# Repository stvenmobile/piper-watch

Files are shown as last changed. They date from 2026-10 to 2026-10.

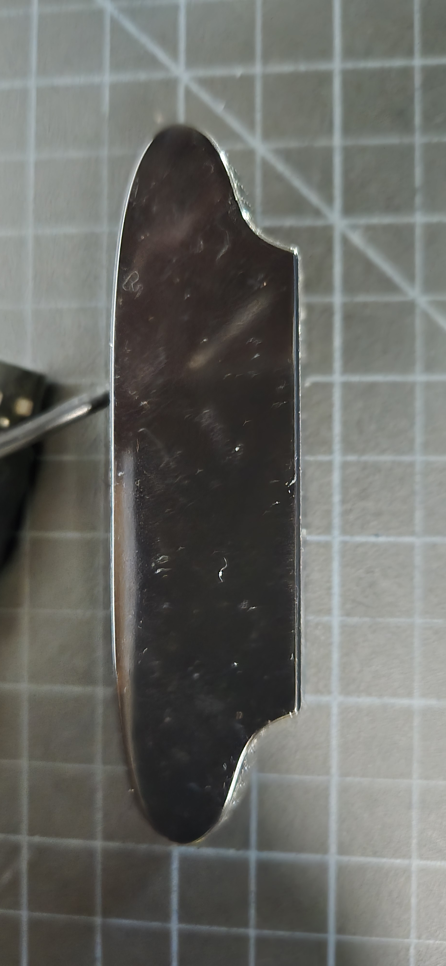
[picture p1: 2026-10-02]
hardware/cad/cam_top.jpg

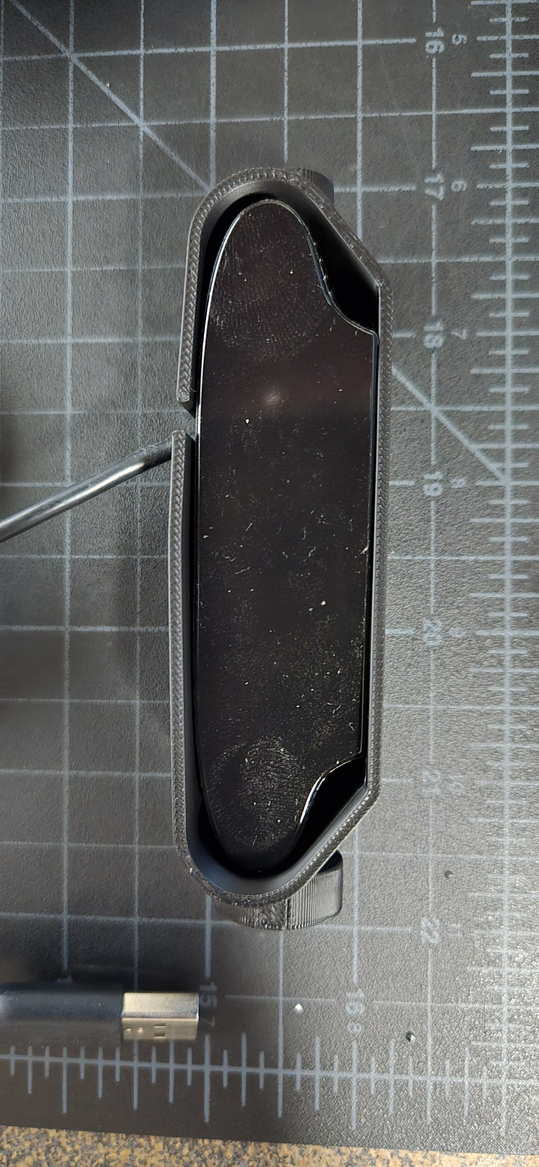
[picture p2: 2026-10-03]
hardware/cad/20261002_183955.jpg

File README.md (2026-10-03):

# Piper-Watch

**Piper-Watch** is the eyes of [piper-assistant](https://github.com/stvenmobile/piper_assistant):
a desktop robot head that turns to look around, finds and follows
faces, and recognises the people it knows. The face is deliberately not a cartoon: a round
face with the camera lens in the middle, framed by a **glowing LED ring** that shows what Piper
is doing (listening, thinking, speaking) and who it is paying attention to.

All the thinking happens on an **NVIDIA Jetson Orin NX** in a separate enclosure. Piper-Watch
itself is a compact two-part unit: a **shallow cylindrical base** (power, an ESP32-S3 controller,
the pan servo) carrying a lazy Susan, and a **head** on a short neck that turns left and right.
There is deliberately **no tilt motor**: the head is fixed at a 15° upward angle by a swappable
wedge, which suits seated conversation. Anything richer than the ring - text, status, the
camera view - goes on the Jetson's dashboard web page.

> **Status:** design phase. The servos are on order; nothing is built yet.

---

## Goals and non-goals

**Goals**
- Smooth, quiet tracking of a person's face (pan), without stepping or buzzing while holding still.
- Simple and stable: one servo, no tilt joint, everything wired inside.
- Face detection and recognition running entirely locally on the Jetson.
- A calm, clearly-a-device presence: the light ring shows Piper's state and points toward the
  person it is attending to, so it reads as an assistant, not a camera that silently watches.
  No eyes or mouth to anthropomorphise (and Piper's voice comes from the speakerphone anyway).
- Compact: a footprint barely larger than the 140 mm lazy Susan, about 20-23 cm tall.
- One data cable and one power brick between the head and the rest of the system.

**Non-goals (for now)**
- A display on the unit. Text, status and the camera view with detection overlays live on
  the Jetson's **dashboard web page** instead.
- Running any AI on the ESP32.
- Battery operation.

---

## System architecture

```text
 ┌─────────────────────── Jetson Orin NX (own enclosure + own PSU) ───────────────────────┐
 │  Vision: capture → face detection → recognition → tracking → pan target + ring state   │
 │  piper-assistant: speech in/out (Piper TTS), dialogue, events                          │
 │  Dashboard web page: camera view + boxes/names/contours (replaces the vector display)  │
 └──────────────┬───────────────────────────────────────────────┬─────────────────────────┘
                │ one USB 2.0 cable                             │ USB
                │                                               │
 ┌──────────────▼──────────── Piper-Watch ──────────────┐  ┌────▼─────────────────────┐
 │  FE1.1s USB 2.0 hub board (fed from the 5 V buck)    │  │ SP-200 speakerphone      │
 │   ├── Logitech C920X camera (stripped) - the "nose"  │  │ 4-mic array, hardware AEC│
 │   └── ESP32-S3 DevKitC-1 N16R8 (native USB)          │  │ placed away from the head│
 │          ├── GPIO 8 → level shifter → 24-LED ring    │  └──────────────────────────┘
 │          │ UART1 @ 1 Mbps (half-duplex servo bus)    │
 │          ▼                                           │
 │  Waveshare Bus Servo Adapter (A) ── 12 V ──┐         │
 │          │ servo bus (daisy-chained)        │         │
 │          └── STS3215  PAN  (ID 1)          │         │
 │                                            │         │
 │                                            │         │
 │  12 V / 5 A brick ── fuse ── star point ───┴── 5 V / 3 A buck ── USB hub power │
 └──────────────────────────────────────────────────────┘
```

The roles are:
- **Jetson:** perception and decisions. It decides *where to look*.
- **ESP32-S3:** real-time body. It decides *how to move there* smoothly and safely,
  reports where the head actually is, and animates the face.
- **Servos:** close their own position loop with a 12-bit magnetic encoder, and report
  position, load, voltage and temperature.

---

## Components

| Part | Role | Status |
|---|---|---|
| NVIDIA Jetson Orin NX (JetPack) | vision, recognition, assistant, dashboard | have |
| **ESP32-S3 DevKitC-1 N16R8** (16 MB flash, 8 MB octal PSRAM, native USB) | controller: pan motor, LED ring, link to the Jetson | have |
| **24-LED WS2812-type ring**: OD 65.6, ID 52.3, 3.2 mm with LEDs; through-hole pads 2× 5 V, 2× GND, DIN, DOUT | the face's light ring | have |
| **74AHCT125** (or a single-gate 74AHCT1G125) level shifter | ESP32 3.3 V data → 5 V ring | needed (~$1) |
| Translucent ring, printed (`ring_diffuser.scad`) in white or natural PLA/PETG | diffuser in front of the LEDs | print |
| **Feetech STS3215, 12 V / 30 kg·cm** serial bus servo: 360° magnetic encoder (4096 steps, 0.088°), position/load/voltage/temperature feedback, 1 Mbps half-duplex TTL bus (2 ordered; the second is a spare) | pan | **ordered** |
| Waveshare **Bus Servo Adapter (A)**: 9–12.6 V input, powers the servo bus and converts it to plain TX/RX for the ESP32 | servo bus interface | needed |
| Logitech **C920X**, housing partly stripped (94 × 24.1 × 29 mm) | camera - the head's "nose" | have |
| **SP-200** USB speakerphone (5 V): 4-mic array, hardware echo cancellation, USB Audio Class | microphone/speaker, connected to the Jetson | have |
| 5.5" (140 mm) aluminium lazy Susan bearing | pan base, carries all vertical load | have / needed |
| 3D-printed base, turntable plate, hollow neck, 15° wedge, and a two-part head (face front + screw-on back) | enclosure | camera pod fit-tested |
| Silicone hook-up wire, ~2 mm, very flexible (6 colours) | display wiring through the neck | have |
| **12 V / 5 A** power brick, inline 5 A fuse, 1000 µF / 25 V capacitor | head power | needed |
| **5 V / 3 A** buck converter | USB hub power | needed |
| **FE1.1s 4-port USB 2.0 hub board** (~$5–7) with external 5V/GND pads and a cuttable "Disable USB Power" jumper (e.g. [Circuitneato](https://circuitneato.com/how-to-use-the-fe1-1s-usb-hub/), or generic "FE1.1s hub module" listings) | one cable to the Jetson | needed |

---

## Power

The servos are the 12 V version, so **the servo bus runs directly from the 12 V brick**
through the Bus Servo Adapter, with no converter in that path. Only the 5 V USB side
needs a buck converter.

```text
12 V / 5 A brick ── 5 A fuse ──┬── 1000 µF ── Bus Servo Adapter (A) ── STS3215 pan servo
                               │
                               └── 5 V / 3 A buck ── FE1.1s hub (5V pads) ──┬── ESP32-S3 (native USB); 5 V → LED ring
                                                                            └── C920X camera
GND: all grounds meet at one star point at the brick input.
```

**Why this layout**
- **Isolation:** the ESP32-S3, LED ring and camera get their 5 V from their own regulator, never
  from the servo rail, so servo current spikes can't reset the ESP32 or glitch the camera. They
  also don't depend on the Jetson's USB ports for power.
- **Efficiency:** the biggest load (the servos) has no conversion losses at all. The 5 V buck
  only carries about 1 A.
- **One cable:** the hub merges the camera and the ESP32-S3 onto a single USB cable to the Jetson.

**USB hub: FE1.1s board**
- **Power:** wire the 5 V buck to the board's **5V/GND pads**. It runs self-powered, at
  500 mA per port (2 A total), which covers the ESP32-S3 (~0.1 A) and the camera (~0.5 A).
  The LED ring is wired to the buck directly, not through the hub.
- **Stop back-feeding:** **cut the "Disable USB Power" jumper** (the name and position vary by
  maker). Otherwise the buck's 5 V flows back up the cable into the Jetson's USB port.
- **Check it before connecting the Jetson:** with only the external 5 V applied, measure the
  upstream port's VBUS pin. It must read **0 V**.
- **Fallback:** the Waveshare USB-HUB-4U (metal case, 5 V DC jack, ~$15–20) works too, but its
  back-feeding behaviour isn't documented, so do the same VBUS check first.

**Power budget (estimates)**

| Load | Typical | Peak |
|---|---|---|
| STS3215 at 12 V, holding | ~0.1 A | |
| STS3215 at 12 V, moving | ~0.3–0.8 A | ~3 A if it stalls |
| ESP32-S3 (5 V) | ~0.1 A | |
| LED ring (5 V), brightness capped at ~25% | ~0.05–0.25 A | ~1.4 A if driven full white (the firmware never does) |
| C920X camera (5 V) | ~0.4 A | ~0.5 A |
| **12 V input total** | **~0.4–1.2 A** | **~3.5 A** |

Normal tracking stays well inside 5 A, and even a full stall of the single servo (jammed, or
pushing against a hard stop) stays under it. Protection:
- Set each servo's **protection current and overload limits** in its EEPROM (see Servo setup),
  so a stall is cut back long before it threatens the brick.
- The **5 A fuse** protects the wiring if something does go wrong.

**The 1000 µF capacitor** at the adapter input absorbs current spikes when the servos
start moving, so the 12 V line doesn't dip.

---

## Wiring and pins (ESP32-S3 DevKitC-1 N16R8)

Pins avoid the ones the N16R8 module and board use internally: GPIO 26-32 (flash),
33-37 (octal PSRAM), 19/20 (native USB), 43/44 (UART0, the board's "UART" port) and the
strapping pins 0, 3, 45, 46.

| Signal | ESP32-S3 pin | Goes to |
|---|---|---|
| Servo bus TX | **GPIO 17** (UART1 TX) | Bus Servo Adapter **RX** |
| Servo bus RX | **GPIO 18** (UART1 RX) | Bus Servo Adapter **TX** |
| Ground | GND | Bus Servo Adapter GND (do not connect its supply to the S3) |
| LED ring data | **GPIO 8** → 74AHCT125 (powered from 5 V) → ring **DIN** | 24-LED ring; DOUT unused |
| LED ring power | 5 V buck / GND | ring 5 V and GND pads (use both pairs) |
| Jetson link + flashing | native USB (the board's **"USB"** port, GPIO 19/20) | USB hub → Jetson, appears as `/dev/ttyACM0` |
| Status LED | on-board RGB (GPIO 48 on v1.0 boards, GPIO 38 on v1.1) | link / fault indication |

**Three wires to the head.** The ring needs only 5 V, GND and one data wire, running about
40-50 cm from the base up through the lazy Susan and the neck (plus the camera cable), so:
- **level-shift the data** to 5 V at the ESP32 end (74AHCT125): WS2812-type LEDs want a 5 V
  logic high, and 3.3 V straight down a long wire is unreliable;
- add a **330 Ω resistor** in series with the data line at the shifter output, and a
  **470-1000 µF** capacitor across 5 V/GND at the ring;
- twist the data wire with a ground wire.

Set the Bus Servo Adapter's jumper for an external UART controller (not its own USB port).
The adapter handles the half-duplex direction switching, so the ESP32 just uses normal TX/RX.

---

## Servo setup (one-time)

1. **ID:** the pan servo stays at the factory **ID 1** (the spare can be set to ID 2 if it is ever
   added). Use Feetech's FD software, the Bus Servo Adapter's USB mode, or a small ESP32 sketch.
2. **Zero before assembly, then centre.** Before fitting a horn or coupling, power each servo and
   command it to **2048 (mid position)**. Only then attach the turntable coupling with the head
   pointing **straight ahead**. That way the mechanism's centre is the servo's
   centre and nothing is under strain at rest. Afterwards, fine-tune with the middle-position
   calibration so that **2048 = straight ahead** exactly. The bench firmware has a
   `center` command for this.
3. **Angle limits in the servo's EEPROM**, so they hold even if the software misbehaves:
   - **Pan:** about ±150° from centre (the camera cable sets the real limit; see Mechanics).
4. **Protection:** set the protection current, overload torque and temperature limits, and enable
   the overload behaviour that drops torque instead of fighting.
5. **Speed and acceleration:** set sensible defaults. The ESP32 overrides them per move.

Library: Feetech's **SCServo** (`SMS_STS` class) for Arduino-ESP32, at 1 Mbps.

---

## Motion control

- The Jetson sends **targets** (pan angle plus a speed hint) at up to 30–50 Hz.
- The ESP32 clamps them to the soft limits, smooths them (a velocity and acceleration
  limit, so tracking looks natural rather than snappy), and writes goal position, speed
  and acceleration to the servo.
- The ESP32 reads back **actual position, load, voltage and temperature** at about 50 Hz,
  timestamps them, and reports them to the Jetson. The Jetson uses the timestamp to work out
  where the camera was pointing when each video frame was taken. This is what keeps tracking
  stable while the head is moving.
- **Watchdog:**
  - no message from the Jetson for **1 s** → hold position;
  - for **10 s** → ease back to the rest pose, then release torque (quiet when idle);
  - over-temperature or overload reported by a servo → stop and report.
- **Power-up:** bus servos don't jump on power-up. The ESP32 reads where they are and
  starts from there.
- **Don't force the head while it's powered.** The STS3215 has no slip clutch: twisting a head
  that is holding position by hand fights the motor and can strip its gears. Two defences:
  - the servo-side **overload and current limits** (Servo setup, step 4) drop torque instead of
    fighting;
  - **torque is released when idle** (watchdog above). To move the head by hand on purpose, release
    torque first (a command from the Jetson or the dashboard), and turn it gently.

---

## Jetson ↔ ESP32 protocol (draft)

- **Link:** the ESP32-S3's native USB serial (`/dev/ttyACM0` on the Jetson). Native USB ignores
  the baud setting and runs at full USB speed.
- **Framing:** binary messages, **COBS**-framed with a **CRC-16**, each with a type byte and a
  sequence number. Unknown types are ignored, so either side can be updated first.

| Direction | Message | Contents |
|---|---|---|
| Jetson → ESP32 | `HEARTBEAT` | sequence, Jetson time |
| Jetson → ESP32 | `LOOK` | pan°, max speed, mode (track / glance / rest) |
| Jetson → ESP32 | `FACE` | state (idle, listening, thinking, speaking, sleeping, error, …), attention direction, colour/brightness |
| Jetson → ESP32 | `CONFIG` | soft limits, smoothing, ring brightness limit, etc. |
| ESP32 → Jetson | `STATUS` | actual pan, load, voltage, temperature, ESP32 time, flags |
| ESP32 → Jetson | `EVENT` | watchdog/fault, boot |

The message set stays small: no video or vector data crosses this link.

---

## The face

A round face (about 105 mm across - the smallest circle around the camera) with the camera lens
in the middle, framed by a glowing ring. The ring is a 24-LED WS2812-type ring behind a
translucent diffuser, and the ESP32-S3 animates it from a single state (`FACE` message):

| State | Ring |
|---|---|
| **Idle** | a steady, soft warm glow |
| **Listening** | slow "breathing" |
| **Thinking** | a short comet running around the ring |
| **Speaking** | a quick, slightly irregular pulse while Piper's TTS plays |
| **Attention** | a brighter arc pointing toward the person being tracked |
| **Sleeping** | a dim ember |
| **Error** | amber flashes |

Brightness is capped at about 25%: plenty behind the diffuser, easy on the 5 V supply, and a
soft warm-white ring also lights the person's face a little, which helps detection in a dim
room. (No red ring - that reads as HAL 9000.)

**Light path.** From the face inward: a 2 mm **diffuser ring** (printed in white or natural
filament, pressed in flush with the face) → a 3.5 mm **air gap** where each LED's light spreads
into its neighbours → the LEDs, facing forward. The ring sits in a pocket behind the gap, held
with a few dabs of hot glue. Its four power pads (15 mm apart) go at the **top** and the two data
pads at the **bottom**; single header pins soldered into the pads take Dupont plugs, which point
straight back above and below the camera (never at the sides, where the camera is right
behind the ring).
Three thin spokes cross the air gap to hold the centre of the face; they fall between LEDs.
The camera sits just behind the ring, its lens at the bottom of a flared opening (16 mm at
the lens, 31 mm at the face, so it doesn't clip the view). Everything else - text, status, the
live camera view with boxes and names - goes on the Jetson's **dashboard web page**.

---

## Vision pipeline (Jetson)

- **Capture:** C920X via V4L2, MJPEG at 720p30 (1080p if needed). Once mounted, **lock focus and
  exposure** with `v4l2-ctl`, because autofocus hunting looks bad while tracking.
- **Face detection:** SCRFD or a YOLOv8-face model under **TensorRT**.
- **Recognition:** **ArcFace** embeddings (InsightFace), matched against a local gallery.
  **Enrolment** is a short guided capture of several angles. Embeddings stay on the Jetson, and
  a "forget me" command deletes a person.
- **Tracking:** keep a track ID per face. Turn the face's **horizontal** position into a pan
  target using the camera's field of view and the head pose *at the time of that frame* (from
  `STATUS`), with a deadband so the head isn't constantly making tiny corrections. **Vertically**
  there is no motor: the camera's ±21° view around its fixed 15° tilt covers seated faces, and
  the Jetson can crop the 1080p frame to centre on it.
- **Behaviour (piper-assistant):** who to look at (speaker, newcomer, recognised person),
  idle glances, a rest pose, and ring states that match the conversation.

---

## Mechanics

Pan only - no tilt motor. Bottom to top:

- **Base:** a shallow cylinder about 146 mm across and 8 cm tall, just larger than the lazy Susan.
  It holds the ESP32-S3, Bus Servo Adapter, 5 V buck and USB hub, with the pan servo in the middle
  and the power input and USB cable at the back. Its top has the raised plinth (outer ring only)
  with M5 heat-set inserts.
- **Pan:** the lazy Susan carries all the weight above it. The pan servo only *turns* the
  turntable plate (on the inner ring) through a coupling at the centre, so there's no sideways
  load on the servo shaft. Soft limits about ±150°.
- **Neck:** a short hollow, chamfered square column (about 40 × 40 mm outside, **28 × 28 mm inside**)
  on the turntable plate. Every wire to the head runs inside it.
- **Wedge:** a small printed block between neck and head, hollow for the wires, that sets the
  head's fixed **15° upward tilt** for seated conversation. To change the angle, print another
  wedge (10°, 20°, ...) and swap it - two or three screws. There's no hinge, so nothing can creep.
- **Head:** round, about 105 mm across and about 45 mm deep, in two parts:
  - **Front (the face):** carries everything: the flared lens opening in the middle, the LED ring
    and its diffuser around it, and the camera cradle behind.
  - **Back cover:** encloses the electronics and wiring and **screws onto the front** (M3 screws into
    heat-set inserts). Assembly and repair: mount the parts to the face, plug in, feed the wires
    down through the wedge and neck, screw on the back.
- **Cables:** the camera's USB cable plus the ring wiring (three 2 mm silicone hook-up wires:
  5 V, GND, data) run from the head down the neck, through the lazy
  Susan's 89 mm opening, into the base, with a **service loop** in the base for the ±150° of pan.
  Nothing is visible from outside. Avoid slip rings for USB 2.0.
- **Noise:** the STS3215 is quiet when holding still. If movement noise still reaches the
  speakerphone, have piper-assistant pause or flag speech recognition while the head moves.

---

## Repository layout

```text
firmware/head/   PlatformIO project for the ESP32-S3 controller (pan motor, LED ring, Jetson link)
jetson/          Jetson-side Python: vision, tracking, head link, dashboard
hardware/        CAD for printed parts, wiring diagrams
docs/            design notes, protocol spec
tools/           servo ID / calibration helpers, bench tests
```

Face images and embeddings are never committed (`jetson/data/` is git-ignored), because this
repository is public.

---

## Roadmap

1. **Bench:** ESP32-S3 + pan motor driver, plus the LED ring through its level shifter. Move by
   serial command; bring up the ring states.
2. **Head v1:** printed base, turntable plate, neck, wedge and two-part head; pan servo, limits,
   watchdog, `STATUS` reporting.
3. **Face:** ring states, the attention arc that follows the tracked person, and the `FACE` message.
4. **Vision:** detection and tracking on the Jetson closing the loop through `LOOK`.
5. **Recognition:** enrolment, gallery, names on the dashboard and in the assistant.
6. **Dashboard:** camera view with overlays on the Jetson's web page.

## Open questions

- Final pan range, which depends on the cable routing.
- Diffuser: filament and thickness for an even glow (print a test ring first).
- Pan drive: central direct drive or offset belt (affects cable routing through the base).

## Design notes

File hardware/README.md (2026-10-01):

# Hardware

- `cad/`: 3D-printable parts (tilt yoke, camera housing, pan coupling, enclosure)
- `wiring/`: wiring diagrams and photos

The bill of materials, power design and pin table are in the main README.

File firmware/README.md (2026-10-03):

# Firmware

`head/` is the PlatformIO project for the controller, an **ESP32-S3 DevKitC-1 N16R8**
(16 MB flash, 8 MB octal PSRAM). It drives the STS3215 servo bus, animates the two OLED eyes
and talks to the Jetson over native USB serial.

Connect the board's **"USB"** port (native USB, not the "UART" port), then:

    cd firmware/head
    pio run -t upload        # build and flash
    pio device monitor       # serial output

The current sketch is a face bring-up test: it reports whether each display answers (eyes on
I2C0 at 0x3C / 0x3D, SDA 8 / SCL 9; mouth on I2C1 at 0x3C, SDA 10 / SCL 11), then the eyes blink
and glance while the mouth alternates between talking and smiling.

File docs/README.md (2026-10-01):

# Docs

Design notes that outgrow the main README, for example the full Jetson ↔ head protocol spec
and servo calibration records. Reference: [LCDWiki E32R40T](https://www.lcdwiki.com/4.0inch_ESP32-32E_Display).

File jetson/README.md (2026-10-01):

# Jetson side

Runs on the Jetson Orin NX. Planned modules:

- `piper_watch/link.py`: the Jetson ↔ head protocol (COBS + CRC-16 over USB serial)
- `piper_watch/vision/`: capture, face detection (SCRFD / YOLOv8-face) and recognition (ArcFace)
- `piper_watch/track.py`: turns face positions into pan/tilt `LOOK` targets
- dashboard: camera view with overlays, served on the Jetson

Face images and embeddings live in `jetson/data/`, which is git-ignored and never leaves the Jetson.

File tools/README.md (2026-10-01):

# Tools

Helper scripts, for example setting STS3215 IDs (new servos all ship as ID 1),
writing angle limits and centre calibration, and a bench test for the servo bus.

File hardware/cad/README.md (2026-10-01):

# CAD (OpenSCAD)

All printed parts are parametric OpenSCAD models. Every dimension lives in
[`params.scad`](params.scad); change a number there and every part follows.

```text
params.scad          dimensions, clearances, printer settings (EST = estimate, to be measured)
vitamins/            simple models of bought parts (lazy Susan, STS3215, ...) for fit checks
parts/               printable parts, one file each
assembly.scad        everything together, to check fit and range of motion
export.sh            render parts/ to out/*.3mf for Bambu Studio
```

## Setup

1. Install an OpenSCAD **development snapshot** (openscad.org → Downloads → Development
   Snapshots), not the old 2021.01 release.
2. *Edit → Preferences → Advanced → Backend:* **Manifold**. Full renders take seconds instead of minutes.
3. Later parts will use the **BOSL2** library (rounded edges, screw holes, attachments). Install
   it into OpenSCAD's library folder (*File → Show Library Folder*) as `BOSL2`.

In OpenSCAD, **F5** previews (fast, for looking), **F6** renders (exact), and **F7** exports
the rendered part.

## Print first

1. **`parts/tolerance_coupon.scad`**: tells us the hole clearance and heat-set insert bore that
   work on this printer with PETG. Update `clr_hole`, `insert_m3` and `insert_m4`.
2. **`parts/ls_gauge.scad`**: a 2 mm ring with slotted holes and tick marks. Lay it on the
   real lazy Susan and read off the true bolt-circle diameters (the numbers next to the ticks).
   Update `ls_outer_bc`, `ls_inner_bc` and `ls_hole_d`.

Then every later part (pan base, turntable top, tilt yoke, camera cradle, box) is built on
measured numbers.

## Printing defaults (A1, 0.4 mm nozzle, PETG)

- At least 4 walls (about 1.8 mm) on load-bearing parts.
- Orient parts so the load runs along the layers, not across them.
- Use M3/M4 brass heat-set inserts where screws go in more than once.

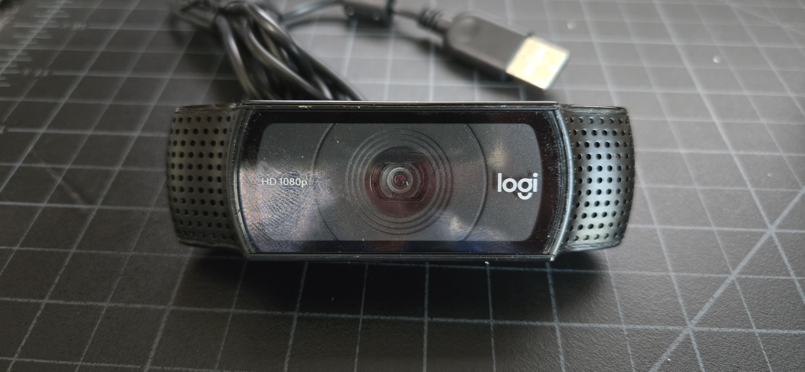
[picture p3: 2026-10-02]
hardware/cad/cam_front.jpg

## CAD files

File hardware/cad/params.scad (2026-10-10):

// Piper-Watch - all dimensions in one place (millimetres).
// Values marked EST are estimates; correct them after measuring the real part.

$fn = 96;                        // circle smoothness for previews/exports

// --- Printing: Bambu Lab A1, 0.4 mm nozzle, PETG -------------------------------
line_w      = 0.45;              // extrusion width
wall        = 4 * line_w;        // 1.8 mm: minimum for load-bearing walls
bed         = [225, 225, 225];   // build volume
clr_hole    = 0.30;              // added to bolt hole diameters - measured: +0.3 is the smallest free fit (coupon, 2026-10-01)
// FIT CALIBRATION (fit_calibration.scad; 15% gyroid, 4 walls, 5 top/bottom; Bambu profiles with
// NO slicer compensation - the CAD compensates). Pick the material the part is printed in:
material   = "PETG";             // "PETG" = Bambu PETG Basic (base parts), "PLA" = Bambu PLA Basic
//   PLA  (2026-10-04): holes ~0.4 small on the diameter (4..15 mm); pins/outer edges ~0.1 small;
//                      X/Y -0.45% (80 -> 79.6 / 79.7); Z true.
//   PETG (2026-10-07): holes 0.29..0.48 small (mean 0.39; 4..6 mm ~0.46, 8..15 mm ~0.32);
//                      pins 0.19..0.22 small; X/Y -0.30% (79.74 / 79.78); Z true (30.02);
//                      first layer slightly squashed (4.00 plate -> 4.11).
cal_hole   = 0.4;                                    // add to a hole's diameter to get it as drawn
cal_edge   = material == "PLA" ? 0.1 : 0.2;          // add to an outside dimension
cal_xy     = material == "PLA" ? 1.0045 : 1.0030;    // scale long X/Y distances (bolt circles, spans)
hole_shrink = 0.6;               // MEASURED on the turntable pulley (PLA, 15% gyroid, 4 walls): a 6.0 hole printed 5.4.
                                 //   Larger PLA parts: draw a hole this much bigger than the size you want.
clr_fit     = 0.35;              // gap for parts that slide/rotate against each other (a little looser than clr_hole)

// --- Fasteners ------------------------------------------------------------------
m3          = 3.0;
m4          = 4.0;
insert_m3   = [4.1, 5.0];        // heat-set insert bore [diameter, depth] - coupon "M3a" confirmed
insert_m25  = [3.6, 4.5];        // EST - M2.5 inserts (~3.5 OD): print a coupon before the body
insert_m4   = [5.6, 6.0];        // coupon "M4a" confirmed
m5          = 5.0;
insert_m5   = [6.4, 7.0];        // EST - confirm with parts/m5_coupon.scad

// --- Lazy Susan: 140 mm round aluminium turntable bearing (Amazon B08CSMCRC6) ----
// Two COPLANAR rings, both 10.5 mm thick and flush top and bottom, with a 0.8 mm gap.
// The outer ring screws down into the box (countersinks on top); the inner ring
// screws up into the turntable top plate (countersinks underneath). No access hole.
ls_od        = 140;              // outer ring, outside (measured)
ls_ring_w    = 12.4;             // radial width of each ring (measured)
ls_gap       = 0.8;              // radial gap between the rings (measured)
ls_outer_id  = ls_od - 2 * ls_ring_w;            // 115.2  outer ring, inside
ls_inner_od  = ls_outer_id - 2 * ls_gap;         // 113.6  inner ring, outside
ls_id        = ls_inner_od - 2 * ls_ring_w;      // 88.8   centre opening (measured ~89)
ls_h         = 10.5;             // thickness of both rings (measured)
ls_hole_d    = 5.05;             // through holes, countersunk (measured 5.05; M5 passes) -> M5 flat-head screws
ls_outer_bc  = 128.0;            // measured: 133 edge-to-edge across opposite holes - hole dia (ring-centre estimate 127.6)
ls_inner_bc  = 101.0;            // measured: 106 edge-to-edge across opposite holes - hole dia (ring-centre estimate 101.2)
ls_holes     = 4;                // per ring, 90 degrees apart
ls_inner_rot = 45;               // inner holes sit between the outer ones

// Mounting rules that follow from the flush rings
ls_clear     = 1.0;              // keep printed parts this far (diameter) from the other ring
top_plate_d  = ls_inner_od - ls_clear;           // 112.6  turntable plate touches the inner ring only
plinth_id    = ls_outer_id + ls_clear;           // 116.2  box-top plinth touches the outer ring only
plinth_h     = 2.0;              // raised plinth height = clear gap under the inner ring

// --- Feetech STS3215 (12 V / 30 kg.cm) - EST from datasheet, verify on arrival --
sts_body     = [45.2, 24.7, 35]; // length x width x height (without horn)
sts_shaft_x  = 11.5;             // EST: output shaft centre from the near end
sts_horn_d   = 20;               // EST: horn diameter
sts_horn_h   = 3;

// --- Pan-only head on a neck (no tilt motor) ----------------------------------------
head_size    = [105, 45, 105];   // round face: diameter, depth (final ~45), diameter
head_tilt    = 15;               // fixed upward tilt, set by the swappable wedge
neck_out     = 40;               // EST: chamfered square neck, outside
neck_in      = 28;               // inside opening: camera USB plug + ~10 x 2 mm silicone wires

// --- GT2 timing belt (6 mm) and printed pulley teeth -----------------------------------
// Tooth-space shape is tunable: print parts/pulley_test_arc.scad and adjust until the belt
// seats fully with no rocking.
gt2_pitch    = 2.0;              // tooth pitch
gt2_pld      = 0.254;            // pitch line sits this far outside the pulley's tooth tips
gt2_belt_w   = 6.0;              // belt width
gt2_belt_t   = 1.5;              // belt total thickness, teeth included (measured)
gt2_tooth_h  = 0.75;             // belt tooth height
gt2_depth    = gt2_tooth_h + 0.05;   // tooth-space depth (belt tooth + clearance) - fits (test arc 1)
gt2_tip_r    = 0.555 + 0.05;     // rounded bottom of the tooth space
gt2_mouth    = 1.35;             // tooth-space width at the tips

// --- Face LED ring: 24-LED WS2812-type ring (measured / vendor) ------------------------
// Through-hole pads (2x 5 V, 2x GND, DIN, DOUT); wires can leave from either side.
ring_od      = 65.6;             // outer diameter
ring_id      = 52.3;             // inner diameter
ring_t       = 3.2;              // PCB (1.6) + 5050 LEDs
ring_n       = 24;               // LEDs, 15 deg apart (~7.7 mm)

// Diffuser in front of the LEDs (ring_diffuser.scad), pressed into the face flush
diff_t       = 2.0;              // thickness
diff_w       = 6.5;              // radial width
diff_clr     = [0.25, 0.45];     // [inner, outer] clearance each side. Fit test 3: diffuser 0.15/0.15 bound
                                 //   at both edges. Then 0.25/0.25 printed 53.2 / 64.5 but the stand's seat
                                 //   printed 52.2 / 64.2 (outer wall at the bed shrinks) -> outer 0.45: CONFIRMED, drops in smoothly

// --- Eyes: 1.28" round TFT, 240 x 240, GC9A01, SPI (MTDELE; vendor listing - re-check on arrival).
// The board is ROUND, concentric with the display, plus a tab carrying the 7 pins.
eye_board_d  = 37.5;             // round board
eye_glass_d  = 35.3;             // round glass, concentric
eye_active_d = 32.4;             // visible (pixel) circle
eye_tab      = [22.7, 8.0];      // pin tab: width, length beyond the circle (overall height 45.5)
eye_t        = 3.2;              // board + glass, without pins
eye_tab_hole_d = 2.0;            // EST: two small holes at the tab's outer corners
eye_tab_hole_x = 9.0;            // EST: their distance either side of the centre line

// --- Mouth: 2.08" white OLED, 256 x 64, SH1122, 4-wire SPI (GME25664-65; vendor drawing:
// 2_08-white_OLED_2.jpg). X along the board's length, from the pin end; Y across.
oled_pcb     = [75.5, 20.6];     // board
oled_t       = 5.6;              // max, board + glass (board 1.2)
oled_holes   = [72.0, 15.5];     // 4 x d2.5 mounting holes, centred on the board
oled_hole_d  = 2.5;
oled_glass   = [62.5, 20.6, 1.63];   // glass starts 7.25 from the pin end
oled_glass_x = 7.25;
oled_va      = [53.18, 14.78];   // visible area: starts 7.25 + 2.10 from the pin end, centred across
oled_va_x    = 7.25 + 2.10;
oled_aa      = [51.18, 12.78];   // active (pixel) area, 1 mm inside the visible area
oled_va_dx   = oled_va_x + oled_va[0] / 2 - oled_pcb[0] / 2;   // -1.82: visible area's centre, off the board's
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

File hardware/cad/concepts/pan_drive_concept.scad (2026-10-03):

// Pan drive concept - ROUGH DRAFT for discussion, not a printable part.
// Stack, bottom to top: reComputer J4012 case -> saddle (air gap over its ribbed top) -> base
// (NEMA17 + belt + electronics) -> lazy Susan -> turntable plate with the hanging ring pulley
// -> neck. Origin: centre of the lazy Susan's bottom face. F5 to look around.
include <../params.scad>
use <../vitamins/lazy_susan.scad>

show_base_shell = true;      // set false to see inside
cutaway         = true;      // cut the base shell in half
show_top        = true;      // lazy Susan, turntable plate, neck and the base's top deck

// ---- sizes (draft) ---------------------------------------------------------------
case_sz   = [121, 130, 61];  // reComputer J4012
saddle_h  = 13;              // air gap over the ribbed top
base_h    = 52;              // base: from saddle deck to the plinth top
plinth_h2 = 2;

ring_T    = 100;             // ring pulley teeth (GT2, 2 mm pitch)
motor_T   = 20;              // motor pulley teeth
R  = ring_T * 2 / PI / 2;    // 31.8  pitch radius
r  = motor_T * 2 / PI / 2;   //  6.4
C  = 45;                     // centre distance (slotted mount: tension by sliding the motor out)
motor_dir = 45;              // motor sits on the diagonal, inside the case footprint
belt_w  = 6;
belt_z  = -14;               // belt plane (below the lazy Susan, inside the base)
nema    = [42.3, 42.3, 23];  // pancake NEMA17
hollow_d = 48;               // cable passage through the ring pulley

// belt length for this centre distance (closed loop)
belt_L = 2 * sqrt(C^2 - (R - r)^2) + PI * (R + r) + 2 * (R - r) * asin((R - r) / C) * PI / 180;
echo(ratio = ring_T / motor_T, belt_length_mm = belt_L, belt_teeth = belt_L / 2,
     open_belt_travel_deg = 180 - acos((R - r) / C) - 18);

z_case_top = -base_h - saddle_h;

module rbox(sz, r = 6) {     // rounded box, centred in XY, from z = 0
    linear_extrude(sz[2]) offset(r = r) square([sz[0] - 2 * r, sz[1] - 2 * r], center = true);
}

// ---- Jetson case --------------------------------------------------------------------
color("#2a2a2a") translate([0, 0, z_case_top - case_sz[2]]) rbox(case_sz, 5);
color("#3a3a3a") for (x = [-56 : 4 : 56])                       // ribs on its top
    translate([x, 0, z_case_top - 0.5]) cube([2, case_sz[1] - 8, 1], center = true);

// ---- saddle: rim that grips the case top, posts at the corners, open sides for air -----
color("#9aa0a6") translate([0, 0, z_case_top - 6]) difference() {
    rbox([case_sz[0] + 4, case_sz[1] + 4, saddle_h + 6], 7);
    translate([0, 0, -1]) rbox([case_sz[0], case_sz[1], 7], 5);              // grips the case
    translate([0, 0, -1]) rbox([case_sz[0] - 6, case_sz[1] - 6, saddle_h + 10], 4);
    for (a = [0, 90]) rotate(a) translate([0, 0, 6 + saddle_h / 2])        // airflow windows
        cube([200, 90, saddle_h - 4], center = true);
}

// ---- base shell -----------------------------------------------------------------------
if (show_base_shell) color("#b8bcc0", 0.55) difference() {
    translate([0, 0, -base_h]) difference() {
        rbox([case_sz[0] + 4, case_sz[1] + 4, base_h], 7);
        translate([0, 0, 2.5]) rbox([case_sz[0] - 1, case_sz[1] - 1, base_h], 5);
    }
    translate([0, 0, -10]) cylinder(d = ls_id - 4, h = 20);             // centre opening
    if (cutaway) translate([-100, -200, -100]) cube([200, 200, 200]);
}
// top deck with the plinth the lazy Susan's OUTER ring screws to
if (show_top) color("#b8bcc0") difference() {
    translate([0, 0, -plinth_h2 - 3]) rbox([case_sz[0] + 4, case_sz[1] + 4, 3], 7);
    translate([0, 0, -10]) cylinder(d = ls_id - 4, h = 20);
    if (cutaway) translate([-100, -200, -100]) cube([200, 200, 200]);
}
if (show_top) color("#b8bcc0") translate([0, 0, -plinth_h2]) difference() {
    cylinder(d = ls_od, h = plinth_h2);
    translate([0, 0, -1]) cylinder(d = plinth_id, h = 5);
    if (cutaway) translate([-100, -200, -100]) cube([200, 200, 200]);
}

// ---- lazy Susan + turntable plate + neck ------------------------------------------------
if (show_top) lazy_susan();
if (show_top) color("#d0d4d8") translate([0, 0, ls_h]) difference() {                 // turntable plate
    cylinder(d = top_plate_d, h = 4);
    translate([0, 0, -1]) cylinder(d = hollow_d, h = 6);
}
if (show_top) color("#d0d4d8") translate([0, 0, ls_h + 4]) difference() {             // neck stub
    linear_extrude(35) offset(r = 3) square(34, center = true);
    translate([0, 0, -1]) cube([28, 28, 40], center = true);
}

// ---- ring pulley: a tube hanging from the plate through the bearing, teeth at the bottom --
color("#e8a33d") difference() {
    union() {
        translate([0, 0, belt_z + belt_w / 2 + 1]) cylinder(d = 2 * R + 6, h = ls_h - belt_z - belt_w / 2 - 1);  // tube
        translate([0, 0, belt_z - belt_w / 2 - 1.5]) cylinder(d = 2 * R + 5, h = 1.5);   // lower flange
        translate([0, 0, belt_z + belt_w / 2]) cylinder(d = 2 * R + 5, h = 1);            // upper flange
        translate([0, 0, belt_z - belt_w / 2]) difference() {                            // teeth (simplified)
            cylinder(d = 2 * R - 0.5, h = belt_w, $fn = ring_T * 2);
            for (i = [0 : ring_T - 1]) rotate(i * 360 / ring_T) translate([R, 0, -1]) cylinder(d = 1.1, h = belt_w + 2, $fn = 8);
        }
    }
    translate([0, 0, -50]) cylinder(d = hollow_d, h = 100);
}
color("white") rotate(motor_dir + 180) translate([R - 4, 0, belt_z - belt_w / 2 - 1.5]) cylinder(d = 4, h = 1.6);   // homing magnet

// ---- belt ------------------------------------------------------------------------------
color("#222") translate([0, 0, belt_z - belt_w / 2]) linear_extrude(belt_w) difference() {
    hull() { circle(r = R + 1.2); rotate(motor_dir) translate([C, 0]) circle(r = r + 1.2); }
    hull() { circle(r = R); rotate(motor_dir) translate([C, 0]) circle(r = r); }
}

// ---- motor, pulley and slotted mount -----------------------------------------------------
rotate(motor_dir) translate([C, 0, 0]) {
    pulley_bottom = belt_z - belt_w / 2 - 8;                             // hub below the teeth
    color("#555") translate([0, 0, pulley_bottom - 3 - nema[2]]) rbox(nema, 3);
    color("silver") translate([0, 0, pulley_bottom - 1]) cylinder(d = 5, h = 20);   // shaft
    color("#c0c0c0") translate([0, 0, pulley_bottom]) {
        cylinder(d = 16, h = 7);                                         // hub + set screws
        translate([0, 0, 7]) cylinder(d = 2 * r, h = belt_w + 2, $fn = motor_T * 2);
        translate([0, 0, 7]) cylinder(d = 2 * r + 4, h = 0.8);
        translate([0, 0, 7 + belt_w + 1.2]) cylinder(d = 2 * r + 4, h = 0.8);
    }
}
// motor bracket: a shelf from the base wall that the motor's face screws to (slots: slide out
// to tension the belt); the motor hangs below it
color("#8899aa") rotate(motor_dir) translate([C, 0, belt_z - belt_w / 2 - 8 - 3]) difference() {
    translate([-25, -25, 0]) cube([50 + 22, 50, 3]);
    translate([0, 0, -1]) cylinder(d = 23, h = 5);                       // motor's centring boss
    for (sx = [-1, 1], sy = [-1, 1]) hull()
        for (dx = [-3, 3]) translate([sx * 15.5 + dx, sy * 15.5, -1]) cylinder(d = 3.4, h = 5, $fn = 16);
}

// ---- homing sensor (Hall, A3144 / or a plotter endstop) ------------------------------------
color("#3355cc") rotate(motor_dir + 180) translate([R + 4.5, 0, belt_z - belt_w / 2 - 9]) cube([4, 5, 6], center = true);

// ---- electronics (placeholders) ---------------------------------------------------------
module board(pos, sz, col, rot = 0) { color(col) translate(pos) rotate(rot) translate(-[sz[0], sz[1], 0] / 2) cube(sz); }
board([-38, 20, -base_h + 3], [25.5, 63, 12], "#1f6f3f", 0);     // ESP32-S3 DevKitC-1
board([ 35, -38, -base_h + 3], [20, 15, 12], "#7a1f9a");          // TMC2209 module + heatsink
board([-30, -40, -base_h + 3], [43, 21, 14], "#1f4f9f", 0);       // 12 V -> 5 V buck
board([ 5, -45, -base_h + 3], [30, 25, 6], "#2f2f2f");            // FE1.1s USB hub

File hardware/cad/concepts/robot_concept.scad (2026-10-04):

// Whole-robot concept - ROUGH DRAFT for discussion, not a printable part.
// The reComputer J4012 sits on the desk, unmodified. Over it drops a SKIRT (full panels front and
// sides, two short returns at the back corners so the case can't move and its DC jack / USB-C
// stay clear) that carries LEVEL 2: the pan drive, ESP32, driver, buck and the CYD status
// display. On top: lazy Susan, turntable plate + ring pulley, neck, 15 deg wedge and the round
// head. Unplug the cables and the whole robot lifts straight off the Jetson.
// Origin: desk surface under the centre of the case; +Y = front (the Jetson's ports face -Y).
include <../params.scad>
use <../vitamins/lazy_susan.scad>
use <../parts/turntable_pulley.scad>

cutaway = false;          // true: cut away the front half to see inside

// ---- the Jetson ---------------------------------------------------------------------
case_sz = [130.1, 121.1, 58.1];   // measured on the desk (model: 130.1 x 121.1)
case_r  = 8;                      // EST corner radius - take the real value from the case

// ---- skirt + level 2 (draft sizes) -------------------------------------------------------
fit     = 1.0;                    // skirt clearance around the case
skirt_t = 2.5;                    // skirt wall
air_gap = 13;                     // above the Jetson's lid (its fan draws air from there)
return_len = 12;                  // back returns, measured from each back corner
deck    = [146, 146];             // level 2 footprint: covers the 140 mm lazy Susan
lvl2_h  = 55;                     // tall enough for the CYD in its front face
cyd     = [86, 50];               // 2.8" CYD board (landscape)
cyd_win = [61, 46];               // its screen

z_lvl2  = case_sz[2] + air_gap;           // underside of level 2's floor (71.1)
z_top   = z_lvl2 + lvl2_h;                // top of level 2 (126.1)
z_ls    = z_top + plinth_h;               // lazy Susan's underside (on the plinth)

module rrect(sz, r) { offset(r = r) square([sz[0] - 2 * r, sz[1] - 2 * r], center = true); }

// ---- Jetson case ----------------------------------------------------------------------
color("#2a2a2a") linear_extrude(case_sz[2]) rrect(case_sz, case_r);
color("#3a3a3a") for (x = [-58 : 4 : 58]) translate([x, 0, case_sz[2] - 0.5]) cube([2, case_sz[1] - 10, 1], center = true);
// its back panel: DC jack (left), USB / RJ45 (middle), USB-C (right) - from the STEP model
color("#888") translate([0, -case_sz[1] / 2 - 0.2, 0]) {
    translate([-48, 0, 30]) rotate([90, 0, 0]) cylinder(d = 8, h = 1);              // DC jack
    for (x = [-15, 2]) translate([x, -1, 33]) cube([13, 1, 15]);                    // USB stacks
    translate([18.5, -1, 33]) cube([16, 1, 14]);                                     // RJ45
    translate([38.5, -1, 36]) cube([8, 1, 3]);                                       // USB-C
}

// ---- skirt ------------------------------------------------------------------------------
module skirt_2d() {
    inner = case_sz + [2, 2] * fit;
    outer = inner + [2, 2] * skirt_t;
    difference() {
        rrect(outer, case_r + fit + skirt_t);
        rrect(inner, case_r + fit);
        // open back, except a return_len wrap at each corner
        translate([0, -outer[1] / 2]) square([outer[0] - 2 * (case_r + return_len), 2 * skirt_t + 4 * fit], center = true);
    }
}
color("#c9ccd0") difference() {
    linear_extrude(z_lvl2) skirt_2d();
    // vent slots high on the side panels, level with the air gap over the Jetson's lid
    for (sx = [-1, 1], y = [-40 : 10 : 40])
        translate([sx * (case_sz[0] / 2 + 3), y, case_sz[2] + air_gap / 2]) cube([10, 5, air_gap - 3], center = true);
    if (cutaway) translate([-200, 0, -1]) cube([400, 200, 400]);
}

// ---- level 2 -------------------------------------------------------------------------------
color("#c9ccd0") difference() {
    translate([0, 0, z_lvl2]) linear_extrude(lvl2_h) rrect(deck, 10);
    translate([0, 0, z_lvl2 + 3]) linear_extrude(lvl2_h - 6) rrect(deck - [6, 6], 7);        // hollow
    translate([0, 0, z_top - 4]) cylinder(d = ls_id - 4, h = 10);                         // centre opening
    translate([0, deck[1] / 2, z_lvl2 + lvl2_h / 2]) cube([cyd_win[0], 10, cyd_win[1]], center = true);
    for (sx = [-1, 1], y = [-50 : 10 : 50])                                                // level 2 vents
        translate([sx * deck[0] / 2, y, z_lvl2 + 15]) cube([10, 5, 12], center = true);
    if (cutaway) translate([-200, 0, -1]) cube([400, 200, 400]);
}
color("#c9ccd0") translate([0, 0, z_top]) difference() {                                  // plinth
    cylinder(d = ls_od, h = plinth_h); translate([0, 0, -1]) cylinder(d = plinth_id, h = 5);
}
// CYD behind its window
color("#1d3b6e") translate([0, deck[1] / 2 - 3 - 4, z_lvl2 + lvl2_h / 2]) cube([cyd[0], 2, cyd[1]], center = true);
color("#9cc4ff") translate([0, deck[1] / 2 - 2.9, z_lvl2 + lvl2_h / 2]) cube([cyd_win[0] - 2, 0.2, cyd_win[1] - 2], center = true);

// ---- drive (as in pan_drive_concept / turntable_pulley) -------------------------------------
translate([0, 0, z_ls]) lazy_susan();
// the real turntable pulley part, flipped from its print orientation (plate up, tube down)
z_plate_top = z_ls + ls_h + 8;
color("#e8a33d") translate([0, 0, z_plate_top]) mirror([0, 0, 1]) turntable_pulley();
z_belt = z_ls + ls_h - 24.5;
motor_a = -135;                                // motor in a back corner (clear of the CYD)
C = 45; r_m = 20 / PI;
rotate(motor_a) translate([C, 0, 0]) {
    color("#555") translate([0, 0, z_belt - 3 - 8 - 3 - 23]) linear_extrude(23) rrect([42.3, 42.3], 3);
    color("#bbb") translate([0, 0, z_belt - 3 - 8]) cylinder(d = 16, h = 8 + 7);
}
color("#222") translate([0, 0, z_belt - 3]) linear_extrude(6) difference() {
    hull() { circle(r = 33); rotate(motor_a) translate([C, 0]) circle(r = r_m + 1.2); }
    hull() { circle(r = 31.8); rotate(motor_a) translate([C, 0]) circle(r = r_m); }
}
// boards (placeholders): ESP32, stepper driver, buck
color("#1f6f3f") translate([-58, -35, z_lvl2 + 3]) cube([25.5, 63, 12]);
color("#7a1f9a") translate([28, 30, z_lvl2 + 3]) cube([20, 15, 12]);
color("#1f4f9f") translate([30, -10, z_lvl2 + 3]) cube([22, 43, 12]);

// ---- neck, wedge, head ------------------------------------------------------------------------
neck_h = 40;
color("#c9ccd0") translate([0, 0, z_plate_top]) difference() {
    linear_extrude(neck_h) rrect([40, 40], 4);
    translate([0, 0, -1]) cube([28, 28, neck_h + 2], center = true);
}
head_d = head_size[0]; head_depth = 45;
translate([0, 0, z_plate_top + neck_h]) rotate([-15, 0, 0]) translate([0, 0, head_d / 2 + 6]) {
    color("#c9ccd0") rotate([-90, 0, 0]) translate([0, 0, -head_depth / 2]) cylinder(d = head_d, h = head_depth);
    color("#222") translate([0, head_depth / 2, 0]) rotate([-90, 0, 0]) cylinder(d = 31, h = 0.6);   // lens opening
    color("#ffe9b8") translate([0, head_depth / 2, 0]) rotate([-90, 0, 0]) difference() {          // light ring
        cylinder(d = 65, h = 0.8); translate([0, 0, -1]) cylinder(d = 53, h = 3);
    }
}

echo(level2_floor = z_lvl2, lazy_susan_top = z_ls + ls_h, plate_top = z_plate_top,
     belt_z = z_belt, motor_bottom = z_belt - 3 - 8 - 3 - 23, head_top_approx = z_plate_top + neck_h + head_d + 6);

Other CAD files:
hardware/cad/parts/drive_deck.scad
hardware/cad/assembly.scad
hardware/cad/concepts/head_box_concept.scad
hardware/cad/concepts/head_brow_concept.scad
hardware/cad/concepts/head_concept.scad
hardware/cad/concepts/head_eyes_concept.scad
hardware/cad/head.scad
hardware/cad/head_assembly.scad
hardware/cad/head_cam.scad
hardware/cad/level2.scad
hardware/cad/parts/back_panel_test.scad
hardware/cad/parts/camera_pod.scad
hardware/cad/parts/camera_pod_lid.scad
hardware/cad/parts/display_fit_test.scad
hardware/cad/parts/eye_cam_bracket.scad
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

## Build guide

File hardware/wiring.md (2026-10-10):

# Wiring

Two boards carry Piper-Watch's wiring: the **perfboard** on Level 2's floor (stepper driver and
power) and the **XIAO ESP32-S3** in the head (the three displays). Everything talks to the Jetson
over USB; no Wi-Fi or Bluetooth is used, so the XIAO's external antenna stays unplugged (the radio
is never turned on).

> The top-level README's electrical section describes the earlier servo design (USB hub, LED
> ring). This file is the current design.

## Overview

```text
 BACK PANEL                   PERFBOARD (70 x 50, Level 2 floor) - every lead lands on a terminal block
 19 V ── jack ──► FLOOR SPLIT BLOCK (always on) ──┬──► spade leads ─────────────────────► Jetson DC in
                                                  └──► J1 + / − ──► J2 out ──► rocker switch ──► J2 ret ──► F1 3 A slow ──► VM rail
                                                                                                     ├─ TMC2209 VM (+100 µF) ──► J3 ──► NEMA17
                                                                                                     └─ J6 19V/GND ──► LM2596 buck (floor) ──► J6 5V
        split block − = the COMMON GROUND (Jetson −, jack −, perfboard J1 −)

 USB to the Jetson (data, and power for the boards' logic):
   • head XIAO ESP32-S3   - eyes + mouth          (through the turntable's hollow)
   • C920 camera board    - original cable        (through the turntable's hollow)
   • base ESP32-S3        - stepper, Hall sensor  (stays in Level 2)
```

The 19 V is split by a screw terminal block screwed to Level 2's floor: one pair of spade leads
goes to the Jetson, the other to the perfboard's J1. The switch and fuse cover **only the head
side** (stepper and buck). The Jetson's feed never passes through the perfboard or the switch, so switching the head off never pulls the Jetson's power; it's protected by the
19 V supply's own current limit.

All grounds are common. The system's **common ground** is the split block's − terminal: the jack's
−, the Jetson's − and the perfboard's J1 − all land there. On the perfboard, one ground point (★)
gathers the board's grounds and returns to the split block through J1 −: the buck's input and
output, the TMC2209's motor and logic grounds, and
the base ESP32's GND. The ground is never switched or fused.

---

## 1. Perfboard: stepper driver + power (Level 2 floor)

The perfboard carries the fuse, the TMC2209 and the terminals. The buck is the larger Seloky
LM2596S (66 × 36, with voltmeter) on its own M3 bosses beside it, wired to J6. The perfboard
sits on four M2.5 inserts (holes 66 × 46).

### Power

| From | To | Notes |
|---|---|---|
| Jack + / − | floor split block + / − | 16–20 AWG, spade terminals (M3.5 screws); the Jetson's spade leads land here too |
| Split block + / − | J1 + / J1 − | 20 AWG, spade at the block end; the split block's − is the **common ground** |
| J1 + | J2 **out** → rocker switch → J2 **ret** | two 20 AWG wires to the back panel |
| J2 ret | **F1** (6 × 30 mm, **3 A slow-blow**, in PCB clips) → **VM rail** | |
| VM rail | TMC2209 **VM** | short, 20–22 AWG |
| VM rail ↔ star ground | **100 µF / 50 V** electrolytic (35 V is the minimum) | right at the driver's VM/GND pins, polarity! |
| VM rail / star ground | J6 **19V / GND** → LM2596 **IN+ / IN−** | |
| LM2596 **OUT+** | J6 **5V** → perfboard **5 V rail** (Hall only) | **set to 5.0 V with a meter before connecting anything**; OUT− is the same as IN− |

### Layout (70 × 50 perfboard) and parts

Top view, back of the case at the top. Every lead that leaves the board lands on a terminal block,
along the back and left edges only (the front faces the display; the right edge is 2.5 mm from
the wall).

```text
 back of the case
     J2 switch   J1 19V in        J3 motor
 ┌○──[ret out]──[ +   − ]───────[2B 2A 1A 1B]──────○┐
 │[J6 19V]  ═[F1 6x30 3 A slow-blow]═                 │
 │[   GND]                                            │
 │[   5V ]           C1      ┌ VM GND 2B 2A 1A 1B VDD GND ┐
 │[J4 STEP]                  │          TMC2209           │
 │[   DIR ]                  └ EN MS1 MS2 PDN UART CLK STEP DIR ┘
 │[   EN  ]
 │[   HALL]
 │[   3V3 ]
 │[   GND ]
 │[J5 5V  ]  R1 10k       ★ star ground
 │[   GND ]
 │[   OUT ]                                           │
 └○───────────────────────────────────────────────────○┘
     front (display)
```

Connections not shown above (insulated wire on the underside):

- **Ground → star point:** J1 −, J6 GND, both TMC2209 GND pins, C1 −, J4 GND, J5 GND.
- **3V3** (from the ESP32 via J4): TMC2209 VDD, MS1, MS2 (1/16 microstepping), and R1's top end.
- **Signals:** J4 STEP/DIR/EN → TMC2209 STEP/DIR/EN; J5 OUT → J4 HALL, with R1 from that line to 3V3.
- **5 V:** J6 5V → J5 5V.
- **Motor:** TMC2209 2B/2A/1A/1B → J3 (straight up, same order).

| Ref | Part | Notes |
|---|---|---|
| J1 | 2-way 5.08 mm screw terminal | 19 V in from the floor split block (+, −) |
| J2 | 2-way 5.08 mm screw terminal | to the switch (out) and back from it (ret) |
| J3 | 4-way 5.08 mm screw terminal | motor coils |
| J4 | 6-way 2.54 mm screw terminal | to the base ESP32: STEP, DIR, EN, HALL, 3V3, GND |
| J5 | 3-way 2.54 mm screw terminal | Hall sensor: 5V, GND, OUT |
| J6 | 3-way 5.08 mm screw terminal | to the buck: 19V (switched, fused), GND out; 5V back |
| U1 | BTT TMC2209 on 2 × 8 female headers | so it can be swapped; check the pin labels against its silkscreen |
| F1 | 6 × 30 mm (3AG) **3 A slow-blow** in two PCB clips | drill the holes out to ~1.3 mm; clip end-stops to the outside so it can't walk out |
| C1 | 100 µF / 50 V electrolytic | at U1's VM/GND |
| R1 | 10 kΩ | Hall OUT pull-up to 3V3 |

Use 20 AWG wire or solder-filled tracks for the 19 V and ground runs (J1, J2, F1, VM, J6 19V/GND); thin
wire is fine for the logic and the 5 V Hall feed.

### TMC2209 (BTT, STEP/DIR mode) ↔ base ESP32-S3

| TMC2209 pin | Goes to | Notes |
|---|---|---|
| VM / GND (motor side) | VM rail / star ground | |
| VIO (VDD) / GND (logic side) | ESP32 **3V3** / ESP32 GND | logic at 3.3 V: no level shifting needed |
| STEP | ESP32 **GPIO 4** | |
| DIR | ESP32 **GPIO 5** | |
| EN | ESP32 **GPIO 6** | LOW = motor enabled |
| MS1, MS2 | VIO (both HIGH) | **1/16 microstepping** (the firmware will assume this) |
| PDN/UART, CLK, INDEX, DIAG | unconnected | UART tuning can come later |
| 1A, 1B / 2A, 2B | NEMA17 coil 1 / coil 2 | find the pairs with a meter (≈ 2–3 Ω across a coil) |

**Current:** set Vref to about **0.7 V** (≈ 0.9 A RMS on the BTT board's formula) before connecting
the motor. Measure between the trim pot and GND with the driver powered and the motor unplugged.
Never plug or unplug the motor while VM is live.

### Homing sensor (A3144 Hall, on the motor bracket)

| A3144 pin (flat face toward you, left → right) | Goes to |
|---|---|
| 1 VCC | 5 V rail (the A3144 needs 4.5 V or more) |
| 2 GND | star ground |
| 3 OUT | ESP32 **GPIO 7**, with a **10 kΩ pull-up to 3V3** |

The output is open-collector, so the pull-up sets its high level. Pull it up to **3V3, never to
5 V**, which would push 5 V into the ESP32's pin.

### The base ESP32-S3

- It's powered by its USB cable from the Jetson. **Don't** also connect the buck's 5 V to its 5V
  pin: two 5 V sources would fight, and the buck could back-feed the Jetson's USB port.
- The **level shifter** planned for the LED ring isn't needed any more (the ring is retired).

---

## 2. Head: XIAO ESP32-S3 ↔ eyes and mouth

All three displays share one SPI bus (clock, data, DC, reset) and each has its own chip select.
Only the selected display listens, so sharing DC and reset is fine. The firmware resets all three
together at start-up.

### Pin map

| Signal | XIAO pin | GPIO | Left eye (GC9A01) | Right eye (GC9A01) | Mouth (SH1122 OLED) |
|---|---|---|---|---|---|
| 3.3 V | 3V3 | – | VCC | VCC | VCC |
| GND | GND | – | GND | GND | GND |
| SPI clock | D8 | 7 | SCL | SCL | SCL (pin 3) |
| SPI data | D10 | 9 | SDA | SDA | SDA (pin 4) |
| DC | D0 | 1 | DC | DC | DC (pin 6) |
| Reset | D1 | 2 | RST | RST | RST (pin 5) |
| CS left eye | D3 | 4 | CS | – | – |
| CS right eye | D4 | 5 | – | CS | – |
| CS mouth | D5 | 6 | – | – | CS (pin 7) |
| Eye backlight (only if the modules have a BL/BLK pin) | D6 | 43 | BL | BL | – |

Free: D2 (GPIO 3), D7 (GPIO 44) and D9 (GPIO 8). GPIO 3 is an ESP32-S3 strapping pin, so it's
deliberately left unused. "Left" and "right" are as seen from the front.

### Notes

- **Power:** the displays run from the XIAO's **3V3** pin. Two eyes plus the OLED draw roughly
  150–250 mA, well within the XIAO's regulator, and everything stays at 3.3 V logic. The XIAO
  itself is powered over USB from the Jetson.
- **Wire:** thin flexible silicone wire, 26–28 AWG. Solder straight to the display pads, no
  headers: the eyes mount upside down, so their pads are at the top, just under the arch, and
  headers would crowd the camera.
- **Route:** from each display down the inside of the face to the floor, then to the XIAO beside
  the cable hole. Keep about 10 cm per eye and 8 cm for the mouth; a little slack lets you lift the
  face plate off. A dab of hot glue on the face's back keeps the bundle tidy.
- **SPI speed:** the GC9A01 runs happily at 40–80 MHz and the SH1122 at about 10 MHz. The firmware
  sets each device's speed, so they share the bus without trouble.
- **Check the labels:** confirm each module's pin labels on arrival. Some GC9A01 modules have a
  BL/BLK backlight pin; others tie the backlight on.
- **Image orientation:** the eyes are mounted upside down, so the firmware rotates their image 180°.

---

## Open questions

- **The 4.3" JC4827 display in Level 2's front** (it has its own ESP32-S3): either its own USB to
  the Jetson (data and power, a third cable, but it doesn't move), or Wi-Fi with power from the
  buck. If it goes on USB, the buck only feeds the Hall sensor, and that can come from the base
  ESP32's 5V pin instead, so the buck could be dropped.

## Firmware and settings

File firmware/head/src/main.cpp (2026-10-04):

// Piper-Watch controller (ESP32-S3) - phase 1: the Jetson link and the light ring.
//
// Link: newline-delimited JSON over the native USB serial port (/dev/ttyACM0 on the Jetson).
//   Jetson -> ESP32
//     {"t":"HEARTBEAT","seq":812}                         at least every second
//     {"t":"FACE","state":"listening","mood":"warm","attention":-20}   (mood/attention optional;
//                                                          "attention":null clears it)
//     {"t":"CONFIG","max_brightness":64,"ring_offset":0}  (any subset)
//   ESP32 -> Jetson
//     {"t":"STATUS", ...}                                 twice a second
//     {"t":"EVENT","what":"boot"|"watchdog"|"link"}       when they happen
// Unknown messages and fields are ignored, so either side can be updated first.
//
// Watchdog: no HEARTBEAT for 3 s -> the ring drops to a dim amber "offline" ember (and, from
// phase 2, the motor stops).
//
// The ring (24 LEDs on RING_DATA via a 74AHCT125 level shifter) is mirrored on the board's own
// RGB LED (BOARD_RGB) as the average colour, so it can be watched on the bench before the ring
// is wired.
#include <Arduino.h>
#include <ArduinoJson.h>
#include <Adafruit_NeoPixel.h>
#include "ring.h"

#define FW_VERSION "0.2.0"

constexpr uint32_t WATCHDOG_MS = 3000;
constexpr uint32_t STATUS_MS = 500;
constexpr uint32_t FRAME_MS = 20;                    // 50 fps

Adafruit_NeoPixel ringLeds(ring::N, RING_DATA, NEO_GRB + NEO_KHZ800);
Adafruit_NeoPixel boardLed(1, BOARD_RGB, NEO_GRB + NEO_KHZ800);

ring::Face face;                                     // what the Jetson asked for
uint8_t maxBrightness = 64;                          // ~25%: plenty behind the diffuser
float ringOffsetDeg = 0;                             // where LED 0 sits (0 = top, clockwise)
uint32_t lastHeartbeat = 0, heartbeatSeq = 0, framesDropped = 0;
bool linkUp = false;

// ---- outgoing --------------------------------------------------------------------------------
static void sendEvent(const char *what) {
  JsonDocument d;
  d["t"] = "EVENT";
  d["what"] = what;
  if (strcmp(what, "boot") == 0) d["fw"] = FW_VERSION;
  serializeJson(d, Serial);
  Serial.print('\n');
}

static void sendStatus() {
  JsonDocument d;
  d["t"] = "STATUS";
  d["fw"] = FW_VERSION;
  d["up"] = millis();
  d["link"] = linkUp;
  d["hb"] = heartbeatSeq;
  d["state"] = ring::stateName(face.state);
  d["mood"] = ring::moodName(face.mood);
  if (face.has_attention) d["attention"] = face.attention_deg; else d["attention"] = nullptr;
  d["bad"] = framesDropped;                          // lines that weren't valid JSON
  serializeJson(d, Serial);
  Serial.print('\n');
}

// ---- incoming ----------------------------------------------------------------------------------
static void handle(const char *line) {
  JsonDocument d;
  if (deserializeJson(d, line)) { framesDropped++; return; }
  const char *t = d["t"] | "";

  if (strcmp(t, "HEARTBEAT") == 0) {
    heartbeatSeq = d["seq"] | heartbeatSeq;
    lastHeartbeat = millis();
    if (!linkUp) {
      linkUp = true;
      if (face.state == ring::State::Offline) face.state = ring::State::Idle;
      sendEvent("link");
    }
  } else if (strcmp(t, "FACE") == 0) {
    face.state = ring::parseState(d["state"] | (const char *)nullptr, face.state);
    face.mood = ring::parseMood(d["mood"] | (const char *)nullptr, face.mood);
    // "attention": <deg> sets it, "attention": null clears it, no "attention" key leaves it alone
    for (JsonPairConst kv : d.as<JsonObjectConst>()) {
      if (strcmp(kv.key().c_str(), "attention") != 0) continue;
      if (kv.value().is<float>()) { face.has_attention = true; face.attention_deg = kv.value(); }
      else face.has_attention = false;
    }
  } else if (strcmp(t, "CONFIG") == 0) {
    if (d["max_brightness"].is<int>()) {
      maxBrightness = constrain((int)d["max_brightness"], 0, 255);
      ringLeds.setBrightness(maxBrightness);
      boardLed.setBrightness(maxBrightness);
    }
    if (d["ring_offset"].is<float>()) ringOffsetDeg = d["ring_offset"];
  }
}

static void readSerial() {
  static char buf[512];
  static size_t len = 0;
  while (Serial.available()) {
    char c = Serial.read();
    if (c == '\n' || c == '\r') {
      if (len) { buf[len] = 0; handle(buf); len = 0; }
    } else if (len < sizeof(buf) - 1) {
      buf[len++] = c;
    } else {                                         // overlong line: drop it
      len = 0;
      framesDropped++;
    }
  }
}

// ---- output ------------------------------------------------------------------------------------
static void drawFrame() {
  ring::RGB px[ring::N];
  ring::Face shown = face;
  if (!linkUp) shown.state = ring::State::Offline;
  ring::render(shown, millis(), ringOffsetDeg, px);

  uint32_t r = 0, g = 0, b = 0;
  for (int i = 0; i < ring::N; i++) {
    ringLeds.setPixelColor(i, px[i].r, px[i].g, px[i].b);
    r += px[i].r; g += px[i].g; b += px[i].b;
  }
  ringLeds.show();
  boardLed.setPixelColor(0, r / ring::N, g / ring::N, b / ring::N);   // bench mirror
  boardLed.show();
}

void setup() {
  Serial.begin(115200);
  Serial.setTxTimeoutMs(0);                          // never block if the Jetson isn't reading
  ringLeds.begin();
  boardLed.begin();
  ringLeds.setBrightness(maxBrightness);
  boardLed.setBrightness(maxBrightness);
  delay(300);
  sendEvent("boot");
}

void loop() {
  static uint32_t nextFrame = 0, nextStatus = 0;
  uint32_t now = millis();
  readSerial();

  if (linkUp && now - lastHeartbeat > WATCHDOG_MS) {
    linkUp = false;
    sendEvent("watchdog");
  }
  if ((int32_t)(now - nextFrame) >= 0) { nextFrame = now + FRAME_MS; drawFrame(); }
  if ((int32_t)(now - nextStatus) >= 0) { nextStatus = now + STATUS_MS; sendStatus(); }
  delay(1);
}

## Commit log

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2026-10-01 CAD skeleton: params, vitamins, lazy Susan gauge, tolerance coupon
    - params.scad: all dimensions; lazy Susan 140 OD / 85 ID / 10.5 thick with
    estimated 128 / 100 mm bolt circles (marked EST), A1 + PETG print
    settings, M3/M4 insert bores, STS3215 and C920X sizes
    - parts/ls_gauge.scad: slotted ring with mm ticks that reads the real
    bolt-circle diameters off the bearing
    - parts/tolerance_coupon.scad: hole clearance and heat-set insert test
    - vitamins for the lazy Susan and STS3215, assembly preview, export.sh
    (uses Manifold when the OpenSCAD build supports it)
    [assembly.scad, lazy_susan.scad, ls_gauge.scad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]
2026-10-01 params: measured clearances from the tolerance coupon
    +0.3 mm is the smallest free fit for M3/M4 holes on the A1 in PETG;
    the 'a' insert bores (4.1 / 5.6 mm) work best. Sliding fits set to 0.35.
    [params.scad]
2026-10-02 Lazy Susan gauge: self-centring 140 mm OD / 89 mm opening
    The gauge now matches the real bearing's rim and centre opening so it sits
    concentric; slots are clamped inside the ring. Centre opening measured at
    89 mm (listing said 85).
    [ls_gauge.scad, params.scad]
2026-10-02 params: measured lazy Susan ring geometry and mounting rules
    Coplanar rings 12.4 mm wide with a 0.8 mm gap: outer ring 140/115.2,
    inner ring 113.6/88.8. Derived: top plate 112.6 mm (inner ring only),
    box-top plinth ID 116.2 mm x 2 mm high (outer ring only). Vitamin model
    updated to match.
    [lazy_susan.scad, params.scad]
2026-10-02 params: bolt circles at the centre of each ring (127.6 / 101.2 mm)
    Holes are visibly centred in each 12.4 mm ring, 4 per ring at 90 degrees.
    [params.scad]
2026-10-02 Bearing screws are M5: hole size, M5 insert params, M5 test coupon
    The lazy Susan's holes pass M5 cleanly (countersinks sized for M5), so the
    bearing mounts with M5 flat-heads into M5 heat-set inserts. insert_m5 is an
    estimate until parts/m5_coupon.scad is printed and tried.
    [m5_coupon.scad, params.scad]
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2026-10-02 params: C920X measured 94 x 29 mm (depth, face, cable exit estimated from photos); add webcam photos
    [params.scad]
2026-10-02 Camera pod v1: body + friction-fit lid, measured C920X dims
    params: C920X 94 x 24.1 x 29 mm, face 63.5 mm, cable 3 mm exiting 30 mm
    from the nearest end. camera_pod.scad builds the camera's top outline in
    2D (hull of face strip, end circles, back ellipse), grows it with offset()
    for cavity and shell, and extrudes it. Front window, rear cable exit on
    the idler side, servo horn disc and slotted hollow idler axle on the tilt
    axis through the camera's centre. Pivots are placeholders until the servo
    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
    [camera_pod.scad, camera_pod_lid.scad, params.scad]
2026-10-02 Camera pod: open-top cable slot so the camera drops in without unplugging
    [camera_pod.scad]
2026-10-02 params: lazy Susan bolt circles measured with calipers (128 / 101 mm)
    [params.scad]
2026-10-02 Add lazy Susan hole-position test ring (M5 clearance on both bolt circles)
    [ls_hole_test.scad]
2026-10-02 Camera pod: cable slot 1 mm further toward the centre (fit test)
    [params.scad]
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2026-10-02 Camera pod (fit test 2): 4 mm lower, cable slot 4 mm deeper, cap-style lid
    The rim now ends about flush with the camera's top, so the lid became a cap
    with a skirt outside the rim. Front window top lowered 2 mm to keep a sturdy
    strip under the lowered rim. The deeper slot lets the camera seat fully.
    [camera_pod.scad]
2026-10-02 Camera pod: keep the inside-lip lid and its headroom; keep the deeper slot
    Back to full height with the lid lip inside the cavity (user preference);
    the cable slot stays 4 mm deeper so the camera seats fully.
    [camera_pod.scad]
2026-10-02 Tilt bearings: 608ZZ on the servo side, 6803-2RS on the cable side
    The 6803's 17 mm bore takes a hollow axle the USB plug passes through, so
    the cable needs no slot; the servo drives through a misalignment-tolerant
    coupling so the bearings, not the servo, carry the pod.
    [params.scad]
2026-10-02 Camera pod: cable slot another 0.6 mm toward the centre (fit test 3)
    [params.scad]
2026-10-03 Camera pod: 1 mm less headroom above the camera; lid lip 1.6 mm
    [camera_pod.scad]
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2026-10-03 Three-section face: add a 2.23" SSD1305 mouth below the camera nose
    The mouth shares the left eye's I2C bus at 0x3D (reset on GPIO 12). README:
    face section (eyes / nose / mouth, talking animation), FACE message replaces
    EYES, pins, components, head size ~95-100 mm square. Firmware pin defines.
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2026-10-03 Tilt: 608ZZ on both sides with steel axles; wires loop behind the head
    Cables go around the tilt pivot (a loose loop out of the back of the head),
    not through it, so the 6803 hollow axle is dropped. Display wiring is one
    8-core slim stranded patch cable.
    [params.scad]
2026-10-03 Pan-only design: neck, 15 deg swappable wedge, two-part head, round nose
    No tilt motor: the head sits on a hollow neck via a printed 15 degree wedge
    (reprint to change the angle). The head is a face front (eyes, round lens
    opening, mouth, all parts mount to it) plus a screw-on back cover; all wiring
    runs inside the head, wedge and neck. One servo (pan); the second is a spare.
    Vertical tracking via the camera's field of view, eye gaze and cropping.
    Concept model updated (head_concept.scad, explode= shows the back cover).
    [head_concept.scad, params.scad]
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2026-10-03 params: 1.3" eye OLED dimensions from the Hosyond mounting drawing
    Board 35.5 x 33.7, holes 30.3 x 28.0 centres, 2.8 mm thick, 4-pin header
    on the top edge pointing back. The blue batch on hand is non-standard
    (34.6 x 32.0); the new white modules will be used for the eyes.
    [params.scad]
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2026-10-03 Firmware: face bring-up for the new pin layout (fixes the build)
    Both eyes on I2C0 (0x3C / 0x3D), 0.91" mouth on I2C1; the previous commit
    renamed the pin defines without updating main.cpp.
    [main.cpp]
2026-10-03 params: measured 0.91" mouth OLED (38 x 12 board, 30 x 11.5 glass, 2.6 thick)
    [params.scad]
2026-10-03 Head front (face) v1 for a fit test
    Printed face-down, support-free. Eye OLEDs on stepped pillars (hot glue),
    C920X in a cradle with its lens behind a round flared nose opening, 0.91"
    mouth in a shallow pocket with a gap for its pins, four M3 insert bosses for
    the back cover. Layout: eyes at the top, nose 4 mm below centre, mouth
    32 mm below centre.
    [head_front.scad]
2026-10-03 Face: mouth margin matches eye margin (10 mm), bottom boss split in two
    The mouth position is now computed from the eye windows, so the face stays
    symmetric if the eye layout changes.
    [head_front.scad]
2026-10-03 Face 118 mm tall: 19 mm margins above the eyes and below the mouth
    [head_front.scad, params.scad]
2026-10-03 Face: four corner bosses for the back cover, webbed into the corner walls
    [head_front.scad]
2026-10-03 Face v2: glass ~1 mm from the surface, 30-60-90 chin, 110 mm tall
    - Display glass sits in pockets cut into the back of the plate, leaving a
    1 mm lip, so eyes and mouth are nearly flush (was ~3 mm inset); eye
    boards rest on the plate, located by the pins
    - Bottom corners cut as 30-60-90 triangles (15 mm in, ~26 mm up) for a chin
    - Height 118 -> 110 mm: 15 mm margins above the eyes and below the mouth
    - Bosses moved: top pair clear of the eye boards, bottom pair in the jaw
    [head_front.scad, params.scad]
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2026-10-03 Face: round the chin's top corners too (40 mm radius); outline built from tangent arcs
    [head_front.scad]
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2026-10-03 Face: round, camera lens framed by a 24-LED light ring (no eyes)
    Drops the OLED eyes for a calmer, non-anthropomorphic face. 105 mm round
    face; the 24-LED WS2812 ring (OD 65.6) sits behind a 3.5 mm light chamber and
    a press-in 2 mm diffuser (new part ring_diffuser.scad); the camera moves back
    to 9.2 mm behind the face, its lens at the bottom of a 40 deg flared opening.
    Firmware: U8g2 eyes replaced by an Adafruit NeoPixel ring demo (listening,
    thinking, speaking, attention arc, sleep) on GPIO 8 via a 5 V level shifter.
    README: face, wiring, power and protocol updated.
    [head_front.scad, params.scad, ring_diffuser.scad]
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2026-10-03 Face: LED ring rests on its PCB, LED tops exactly 3.5 mm behind the diffuser
    The light chamber now runs down to the PCB: the LEDs sit inside it and the
    board rests on the chamber's edges. Before, the LEDs fitted the chamber, so the
    ring would have sunk 1.6 mm deeper and halved the air gap. Chamber 5.7 mm wide
    for ~0.3 mm LED clearance (LED centres measured at r 29.45).
    [head_front.scad]
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2026-10-03 Pulley clamp: belt is 1.5 mm thick (measured); wider slots, two-clearance test arc
    Test arc 1: teeth fit, clamp slot too tight. Backing channel now 0.75 + 0.05 +
    0.3 mm (was 0.63 + 0.2). Test arc 2 carries both slots: 0.3 mm (plain) and
    0.45 mm (notched base).
    [params.scad, pulley_test_arc.scad, turntable_pulley.scad]
2026-10-04 Face: tighter LED-ring pocket (+0.1 ID / -0.1 OD) and diffuser seat (-0.05 each side)
    Fit test 1: both too loose.
    [head_front.scad]
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2026-10-04 Turntable pulley: fitted clamp slot (1.10 mm channel), M5 through-holes 5.0 with nut pockets
    Test arc 2's 0.3 mm slot fits with no looseness. The first full print's 6.4 mm
    insert bores left ~1 mm of play on the lazy Susan; now 5.0 mm through-holes
    (drill to 5 if tight) and hex pockets for M5 nuts in the plate's top.
    [pulley_test_arc.scad, turntable_pulley.scad]
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2026-10-04 Turntable pulley: M5 holes back to 6.0 - confirmed by the full print
    The printed pulley (6.0 mm holes, PLA, 15% gyroid) takes the M5 bolts with a
    smooth, slip-free fit on the lazy Susan; the later change to 5.3 would have
    been too tight.
    [turntable_pulley.scad]
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2026-10-04 Diffuser: 0.25 mm clearance each edge (bound at both); chamber lip so it still has a ledge
    Fit test 3: LED ring pocket perfect; the diffuser bound at both its inner and
    outer edge (printed holes shrink, printed edges grow). Diffuser now 52.95 /
    64.95 in a 52.55 / 65.45 seat. A 0.6 mm lip at the front of the light chamber
    (5.1 wide) keeps ~0.45 mm ledges for it to rest on.
    [head_front.scad, params.scad, ring_diffuser.scad]
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2026-10-04 Eye test stand + desk foot: bare C920 board behind the LED ring, for bench testing
    Uses the face's own cut-outs (diffuser seat, light chamber, spokes, ring
    pocket). The bare board (80 x 22) snaps onto four tabs on the back, 1.8 mm
    behind the ring; the lens holder passes forward through a square opening, so
    its unmeasured height doesn't matter. Stem with a 1/4"-20 nut pocket (tripod)
    that also plugs into a printed foot tilted 10 deg up.
    [eye_test_foot.scad, eye_test_stand.scad]
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2026-10-04 Eye test stand: measured board (1.3 thick) - snap tabs sized to it
    [eye_test_stand.scad]
2026-10-04 Eye test stand print 2: mic notches, coil bay, catches +0.6
    Print 1: the microphones (6.1 dia, 69.2 between inner edges) and two coils on
    the board's front held it off the back face. Semicircular notches for the mics
    (also index the board side to side), a 4 x 5 mm bay off the left of the clear
    pocket (seen from the back) for the coils, and the snap catches 0.6 mm higher
    for solder joints.
    [eye_test_stand.scad]
2026-10-04 Eye test stand: snap catches 1.0 mm higher than print 1 (was 0.6)
    [eye_test_stand.scad]
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2026-10-04 Eye test stand: one centred bottom tab, 3.1 mm in, for the board's cut-back edge
    Print 2: top tabs and mic notches work; the bottom tabs missed because the
    board's bottom edge is cut back 3.1 mm along its middle. One bottom tab at the
    centre, on a bracket from the pocket wall that stays outside the lens cone.
    [eye_test_stand.scad]
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2026-10-04 Motor bracket: measured NEMA17 (33.4 body, 17.5 shaft) and pulley (belt centre 16.25 up)
    The 20 T pulley sits fully down on the motor, through the plate's 23 mm centre
    hole; motor face 16.25 below the belt line. Clearances re-checked: pulley top
    3.75 below the deck, Hall magnet gap ~4.25, no contact with the turntable
    pulley at 42 mm.
    [level2.scad, motor_bracket.scad]
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2026-10-04 Eye test stand: rigid bottom hook (10 x 2.4, 0.8 lip) instead of a thin flexing tab
    Print 3: everything fits, but the centred bottom tab snapped. The bottom is now
    a rigid hook: fit the board's bottom edge under it first, then press the top
    edge past the two flexing top tabs.
    [eye_test_stand.scad]
2026-10-04 Firmware 0.2: Jetson link (JSON lines) + light-ring renderer with moods and a watchdog
    Phase 1. Newline-delimited JSON over native USB: HEARTBEAT, FACE (state, mood,
    attention), CONFIG (max_brightness, ring_offset) in; STATUS (2 Hz) and EVENT
    (boot, link, watchdog) out. Ring states: offline, idle, listening, thinking,
    speaking, sleeping, error; moods neutral, warm, curious, uncertain, concerned,
    sleepy tint colour, brightness and tempo; an attention arc points at the
    tracked person. No heartbeat for 3 s -> dim amber 'offline'. The ring's average
    colour is mirrored on the board's RGB LED (BOARD_RGB=48) for bench testing.
    [main.cpp]
2026-10-04 Body display window: 45 deg bevel to the glass; posts 1.4 shorter (glass measured 3.6)
    Display fit test: the border round the image is even (window position/size
    right). The glass sat 1.4 mm off the wall with 5.0 posts, so the posts are now
    3.6 long; the insert bores still stop 1.1 mm short of the face. The small outer
    chamfer is now a 45 deg bevel through the whole wall, down to the glass.
    [l2_body.scad]
2026-10-04 Body: display posts 0.6 shorter (not 1.4) - glass flush against the wall
    The fit test's gap was 0.6 mm: glass module 4.4 thick. Insert bores stop 1.9 mm
    short of the face. The 45 deg window bevel stays.
    [l2_body.scad]
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2026-10-06 Camera bracket: U-channel strap over the C920 board, 2 x M3 into heat-set inserts; replaces the snap tabs
    - eye_cam_bracket.scad: 38.4 long (18.4 board + 10 each side), 10 wide, 2.5 thick, bridge
    underside 3.0 above the back face; legs 0.5 off the board edges also locate it up/down;
    holes centred on the flat feet (6.5 from the board edges) so the screw heads clear the legs
    - eye_test_stand.scad: snap tabs off (kept, snap_tabs = false); M3 insert bores (4.1 x 6) under
    the feet; a boss fills the component pocket below the board's cut-back edge round the lower
    insert (it was 0.85 mm from the pocket) and seats the lower leg; 45 deg underside
    - shared dimensions in eye_cam_bracket_dims.sc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
    [eye_cam_bracket.scad, eye_cam_bracket_dims.scad, eye_test_stand.scad]
2026-10-07 PETG Basic calibration (material switch in params.scad); deck/body/bracket holes from cal values; buck bosses in the body
    - params.scad: material = PETG (Bambu PETG Basic, 2026-10-07: holes -0.39, pins -0.2,
    X/Y -0.30%, Z true) alongside the PLA values; cal_edge / cal_xy follow the material
    - drive deck: bolt circle 128 x 1.0030; M3 holes 3.4 + cal_hole (3.6 would print ~3.1);
    M5 nut pockets 8.6 AF (8.3 would print ~7.9 - too tight for an 8.0 nut)
    - body: M3 holes from cal_hole; floor bosses (M3 inserts, 6 high) for the Seloky LM2596S
    buck, holes 54 x 31 measured, front-left, input end to the back
    - motor bracket: M3 holes from cal_hole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
    [drive_deck.scad, l2_body.scad, motor_bracket.scad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]
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2026-10-08 Head concept v3: GC9A01 round TFT eyes, camera as the nose fixed 27 deg up (sized for 4:3 mode), no LED ring; assembly uses it
    [assembly.scad, head_eyes_concept.scad]
2026-10-08 Head concept v4: camera in a half-cylinder brow on top (fixed 18 deg up), GC9A01 eyes, 2.23in OLED mouth; assembly uses it
    [assembly.scad, head_brow_concept.scad]
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2026-10-20 Test stand: pillow block holes on a 32 mm square (measured); M3 insert bores 4.3 (+0.2, the 4.1 was too tight); strap inserts in full round bosses instead of breaking out of thin walls; tilt strap po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
2026-10-20 Test stand base: a hub-sized clearance below the plate (the sleeve's front wall crossed the hub's path); assembly preview draws the pan servo at its true height
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2026-10-21 Servo test stand: openings for the servo's bottom-face block and sockets, hub 2 mm shorter
    - pan strap: one opening for the raised block and the plugs; base legs 17 mm longer for the
    plugs and a cable bend under the servo
    - turret end wall: cut-outs for the tilt servo's block and sockets; strap insert moved to the
    wall's far end (boss trimmed clear of the servo); cable tunnel now starts outside the wall
    - hub: flange 2 mm lower (measured) so the turntable rests on the bearing's flange
2026-10-21 Servo test tools for the STS3215 test stand; fix turret end-wall comments
    tools/servo_test: bus helpers (Waveshare adapter, COM21, 1 Mbaud), read-only ping, centre_here
    (current position -> 2048, stored in the servo), and a sweep with speed/acc options. Pan (ID 1)
    calibrated facing forward; its raw direction is flipped in software so + = left.
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2026-10-21 Servo test tools: set_id, --id on sweep, tilt (ID 2) direction flipped so + = up; centre_here retries after saving
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2026-10-24 Head concept v2: octagonal front outline (15 mm chamfers); contents and nod clearance re-checked
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2026-10-25 Head v2 diffuser: 1.8 mm face (was 2.5, plus a solid 1.5 rim disc behind it by mistake); the rim is now a ring at the edge, reached by a 0.6 mm collar
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2026-10-25 Head v2: the crank and the pivot insert bosses get 45 deg wedges under them back into the side walls (printed face-down they started in mid-air; the first print sagged)
2026-10-25 Head v2 camera mount by its lens holder: the ring + diffuser go in from the front (the face's opening is the ring's bore); behind the ring a back wall with a lip the cube's top stops against and a sq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
2026-10-26 Head v2: the diffuser snaps in - 3 fingers beside the LED ring (centring it) with bumps that click into pockets in the chamber wall - and is a 0.2 tighter press fit; the face's opening grows to 40 fo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
2026-10-26 Head v2 ears 10 mm nearer the middle: the box sits 10 lower round the axle ([-54, 68]) and the axle 10 higher on the turret (link 85, was 75) - same nod clearance and the same servo angles (to 0.03 d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
2026-10-31 head v2 diffuser: +0.2 mm (drawn 40.5), still loose at 40.3; gauge rings 40.4/40.5/40.6
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
